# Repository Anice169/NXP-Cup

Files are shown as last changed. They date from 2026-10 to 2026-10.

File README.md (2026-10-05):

# 🏎️ Autonomous Line-Following Car (inspired by the NXP Cup)

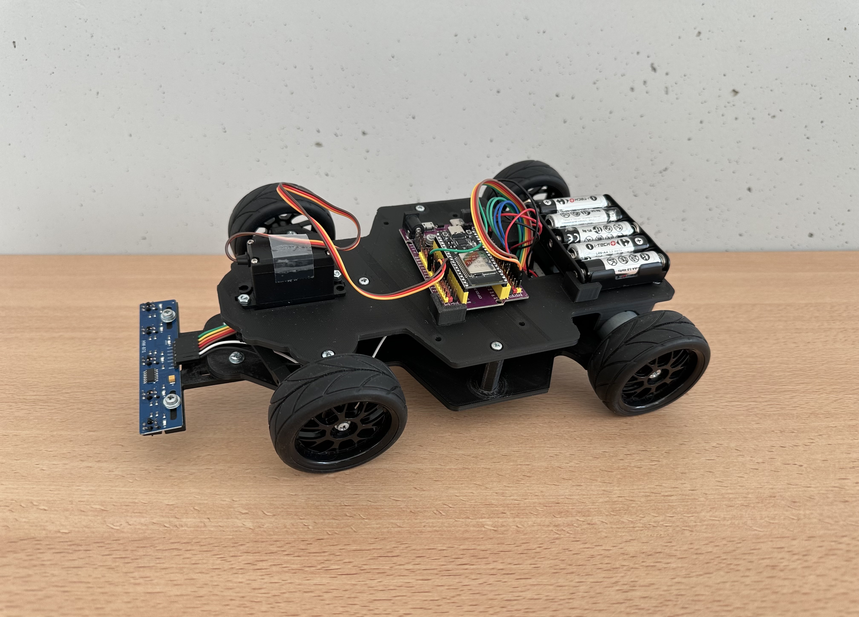
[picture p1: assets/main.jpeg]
Finished car


> Side view of the car once mechanical and electronic assembly was completed.
## 📖 Overview

This project was carried out as part of the 3rd-year project at Polytech Dijon, by a team of three students. We wanted to build skills in embedded electronics and programming, and to discover 3D printing. The NXP Cup inspired us with a concrete goal: building an autonomous car able to follow a line on the ground.

The **NXP Cup** is an international competition organized by NXP Semiconductors, in which teams of students design, build, and program an autonomous miniature vehicle that races around a track as fast as possible. In the official 2025-2026 kit, the car is built on a 3D-printed chassis, driven by an NXP microcontroller, and guided by a camera. More information is available on the [official NXP Cup website](https://nxpcup.nxp.com) and in its [technical GitBook](https://nxp.gitbook.io/nxp-cup).

Rather than using an NXP board, we chose to take on the challenge our own way: we kept the mechanical base of the official kit (motors, servo, wheels, 3D-printed chassis adapted from NXP's files) and redesigned the rest around an **ESP32**.

## 👥 Team

Project carried out by a team of three, as part of the 3rd-year project at Polytech Dijon.

| Member | LinkedIn |
|---|---|
| GUENIAT Anice | [linkedin.com/in/anice-guéniat](https://www.linkedin.com/in/anice-gu%C3%A9niat/) |
| PORTAZ-MONCAYOLA Théo | [linkedin.com/in/theo-portaz-moncayola](https://www.linkedin.com/in/theo-portaz-moncayola/) |
| TENA-FRANCIA Baptiste | [linkedin.com/in/baptiste-tenafrancia](https://www.linkedin.com/in/baptiste-tenafrancia/) |

## 🆚 Official NXP Cup vs. our car

We kept the mechanical base of the official kit and replaced the electronic components that drive the car.

| | Official kit (2025-2026 edition) | Our car |
|---|---|---|
| Control board | NXP board (FRDM-MCXN947, FRDM i.MX93, or S32K144) | ESP32-DevKitC + expansion board |
| Line detection | Pixy2 camera | 5-channel infrared sensor module (TCRT5000) |
| Propulsion | 2 × JGA25-370 motors + DRV8833 drivers | Identical |
| Steering | MG996R servo | Identical |
| Wheels and guidance | 65 mm tires, 12 mm hex couplers, 626ZZ bearing | Identical |
| Power supply | 2S LiPo battery + LM2596 regulators | 5 × AA batteries (motors) + external USB-C battery (electronics) |
| Chassis | 3D-printed (files published by NXP) | 3D-printed from adapted NXP files (see below) |
| Software | NXP tools and examples | C++ (Arduino framework) with PlatformIO |

**Modifications made to the chassis** (based on the 3D files published by NXP):

- Removed the camera mount, no longer needed with infrared sensors
- Added mounts for our components: ESP32 with its expansion board and battery holder
- Added an extension to attach the infrared sensor module, with adjustable height above the ground and distance from the car

## 📸 Demonstration

<p align="center">
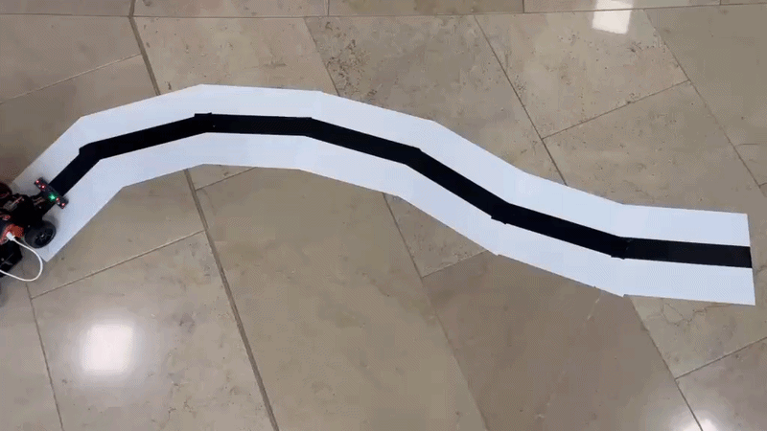
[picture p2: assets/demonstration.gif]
Demonstration of the car following the black line
  <br>
  <em>The car autonomously follows the black line, including curves (top view, about 8 seconds).</em>
</p>

## ✨ Features

- Black line detection using a 5-channel infrared sensor module (TCRT5000)
- Black/white sensor calibration, **saved to flash memory** (no need to recalibrate at every power-up)
- Steering handled by a servo motor
- Propulsion by two geared motors driven through an H-bridge (DRV8833)
- Fully autonomous operation on batteries, with no connection to a computer

## 🔧 Hardware used

| Component | Role |
|---|---|
| ESP32-DevKitC (ESP-WROOM-32) + expansion board | The car's brain: reads the sensors and drives the actuators |
| 5-channel infrared line-following module (TCRT5000) | Detection of the black line on the ground (4 channels used) |
| DRV8833 motor driver (H-bridge) | Controls the speed and direction of the two motors |
| MG996R servo motor | Steering: turns the front wheels |
| 2 × JGA25-370 motors (6 V, 625 rpm) | Propulsion |
| 65 mm tires and 12 mm hex couplers | Wheels and mounting on the motor shafts |
| 626ZZ bearings | Rotation of the front wheels |
| 5 × AA battery holder | Power supply for the motors |
| External USB-C battery | Power supply for the electronics (ESP32, sensors, servo) |
| Breadboard and jumper wires | Wiring |
| 3D-printed chassis (adapted NXP files) | Mechanical structure |

**Software**: VS Code + PlatformIO, Arduino framework for ESP32.

## ⚡ Pinout (ESP32 GPIO)

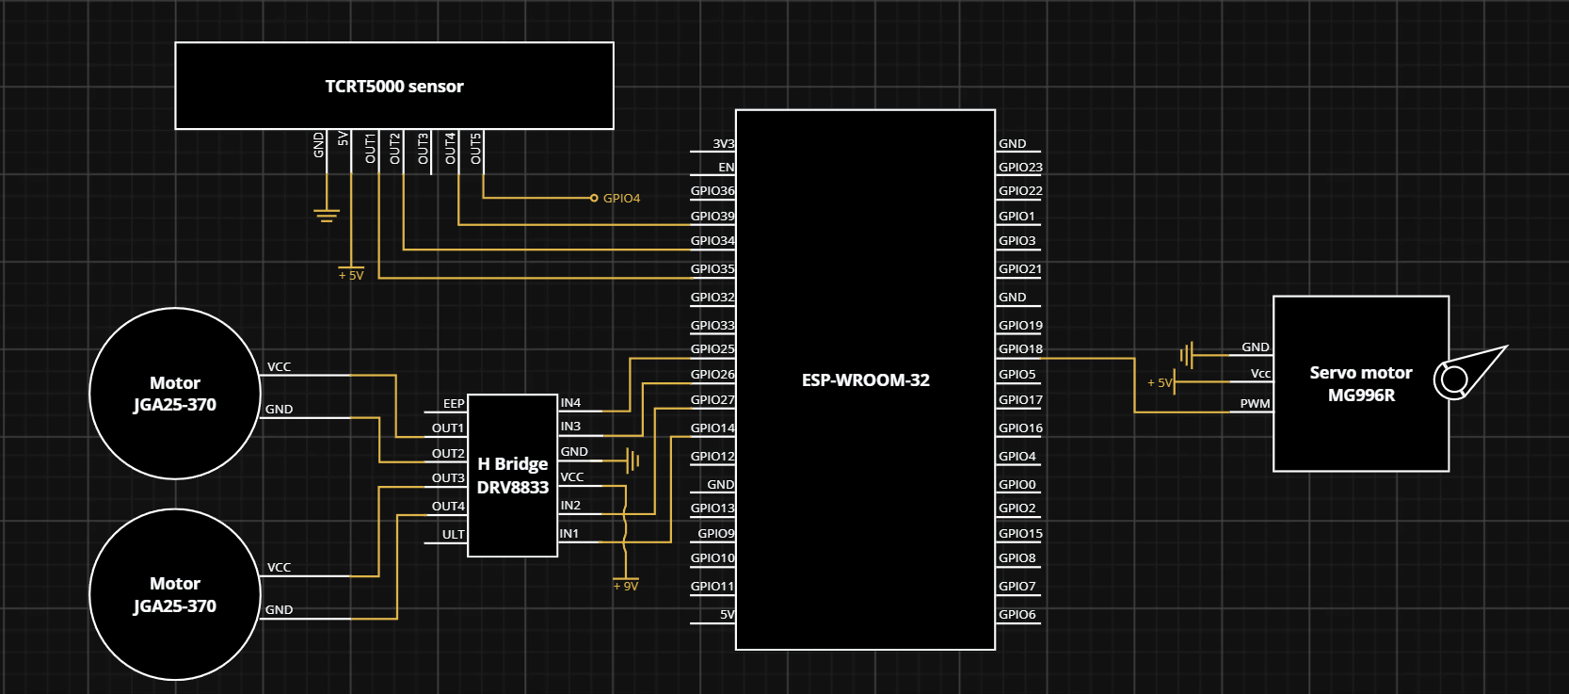
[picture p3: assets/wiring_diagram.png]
Functional circuit diagram

 <!--
| GPIO | Function |
|---|---|
| 25 | DRV8833 — IN1 (motor A) |
| 26 | DRV8833 — IN2 (motor A) |
| 27 | DRV8833 — IN3 (motor B) |
| 14 | DRV8833 — IN4 (motor B) |
| 18 | Servo motor — PWM signal |
| 34 | IR sensor 1 |
| 35 | IR sensor 2 |
| 39 (SVN) | IR sensor 4 |
| 4 | IR sensor 5 |
 -->
> The module's center channel (sensor 3) proved unreliable during the project: it is not used, and the code relies on the 4 remaining channels (1, 2, 4, and 5).
>
> The four DRV8833 inputs receive PWM signals (1 kHz, 8-bit resolution) generated by the ESP32's LEDC peripheral.

## 🧠 How it works
The program (`code/src/main.cpp`) runs in two stages: a startup phase, followed by a decision loop repeated about 20 times per second. The diagram below summarizes how the program works.

```mermaid
flowchart TD
    A["Startup"] --> B{"Calibration<br>in flash memory?"}
    B -- yes --> C["Load calibration<br>+ 10 s to recalibrate with 'c'"]
    B -- no --> D["Guided calibration:<br>white then black"]
    D --> E["Save to flash"]
    C --> F["3 s countdown"]
    E --> F
    F --> G{"More than 100 s<br>since start?"}
    G -- yes --> H["Stop motors<br>servo at 90°"]
    G -- no --> I["Read the 4 sensors<br>normalized from 0 to 1000"]
    I --> J{"Darkest sensor<br>above 300?"}
    J -- no --> K["Servo at 90°:<br>straight ahead"]
    J -- yes --> L["Servo at the angle<br>associated with this sensor"]
    K --> M["Motors at constant speed"]
    L --> M
    M --> N["50 ms pause"]
    N --> G
```

## 🚧 Challenges encountered

- **Fried ESP32**: a mix-up between the 5 V and 3.3 V pins caused short circuit on a board. A multimeter helped us trace the cause of the failure.
- **Insufficient power supply**: the servo motor, the ESP32, and the sensors did not work properly when powered by a single regulated source. We split the power into two supplies: batteries for power (motors) and an external battery for the logic.
- **Unstable center channel on the module**: we gave up using it and adapted the decision algorithm to the 4 remaining channels.
- **Faulty servo motor**: on arrival, one of the servo's gear teeth was defective. We attempted to repair it without success, then ordered a new servo.
- **Broken motor mount**: a 3D-printing defect caused the motor mount to fail on the chassis. We reprinted the part with more robust print settings.

## 🗂️ Repository structure

```
voiture-nxp-cup-esp32/
├── README.md             
├── README.fr.md                  # French readme
├── code/                         # Main code: sensor reading, calibration, control loop
├── cad/                          # 3D Files
└── assets/                       # Pictures

```

## 🚀 Summary and outlook

This project took us through every stage of designing an embedded system: choosing and assembling components, adapting a 3D-printed mechanical structure, programming a microcontroller, and then diagnosing failures, whether from the electronics, the power supply, or a faulty part. The result is a car that follows a line autonomously, and above all a solid foundation to keep building on: finer driving control, speed better adapted to the trajectory, and smarter behavior in unexpected situations are the next steps we're looking forward to.

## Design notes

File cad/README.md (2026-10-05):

# 3D Design – NXP Cup ESP32 Car

This folder contains all the 3D design (CAD) files for the car, created with **Autodesk Fusion 360**.

## Preview

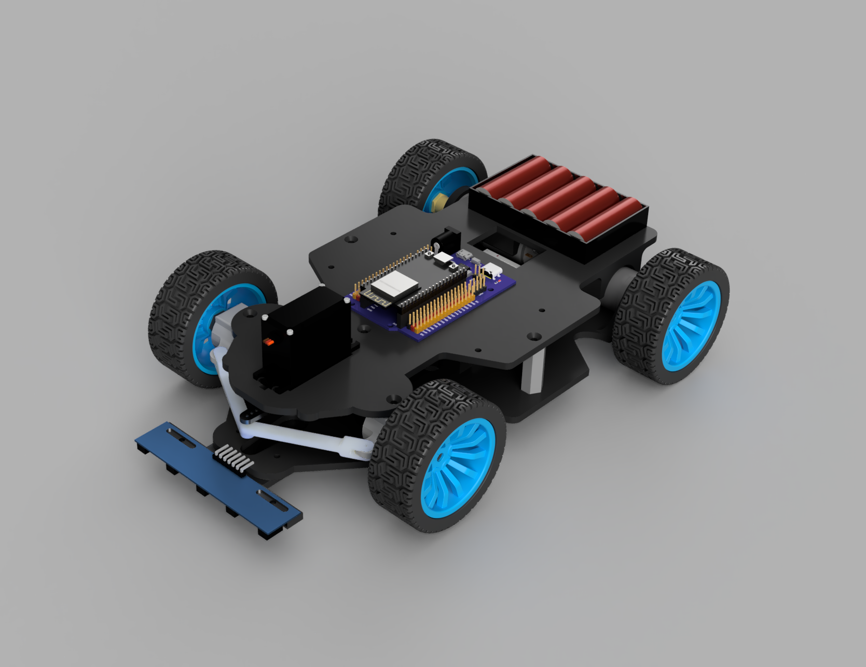
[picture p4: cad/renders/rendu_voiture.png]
3D render of the car


## Folder structure

```
cad/
├── README.md                # This file
├── source/                  # Editable Fusion 360 files (.f3d)
├── step/                    # Universal export (.step)
├── stl/                     # Parts ready for 3D printing
└── renders/                 # Render images
```

| Folder | Content | Purpose |
|---|---|---|
| `source/` | `voiture_complete.f3d` | Original file, editable in Fusion 360 |
| `step/` | `voiture_complete.step` | Neutral format, can be opened with FreeCAD, SolidWorks, Onshape, etc. |
| `stl/` | One part per file | Direct 3D printing, without opening Fusion |
| `renders/` | PNG images | Project presentation |

## Parts list

| Part | STL file | Quantity | Role |
|---|---|---|---|
| Bottom plate | `BottomPlate_Bottomplate.stl` | 1 | Base of the chassis, on which the components are mounted |
| Top plate | `plaque_hautV3.stl` | 1 | Upper deck of the chassis |
| Hex spacer | `Chassis_HexSpacer.stl` | 5 | Keeps the two chassis plates apart |
| Left steering arm | `Arm Steering left.stl` | 1 | Steering arm for the front left wheel |
| Right steering arm | `Arm steering right.stl` | 1 | Steering arm for the front right wheel |
| Front wheel hex adapter | `Steering_HexAdapterFrontWh….stl` | 2 | Connects the front wheel to its axle |
| Steering linchpin | `Steering_Linchpin.stl` | 2 | Locks the steering axle in place |
| Steering shaft | `Steering_SteerShaft.stl` | 2 | Pivot axle of the steering |
| Sensor mount | `support capteur.stl` | 1 | Sensor mounting bracket |
| Mount | `support.stl` | 1 | Bracket used to attach components to the chassis |

## Usage

### Editing the design
1. Open Fusion 360.
2. Go to `File > Open > Open from my computer`.
3. Select `source/voiture_complete.f3d`.

### Using another CAD software
Import the file `step/voiture_complete.step` (FreeCAD, SolidWorks, Onshape, etc.).

### Printing a part
Open the desired `.stl` file in your slicer (Cura, PrusaSlicer, Bambu Studio...) and start the print.

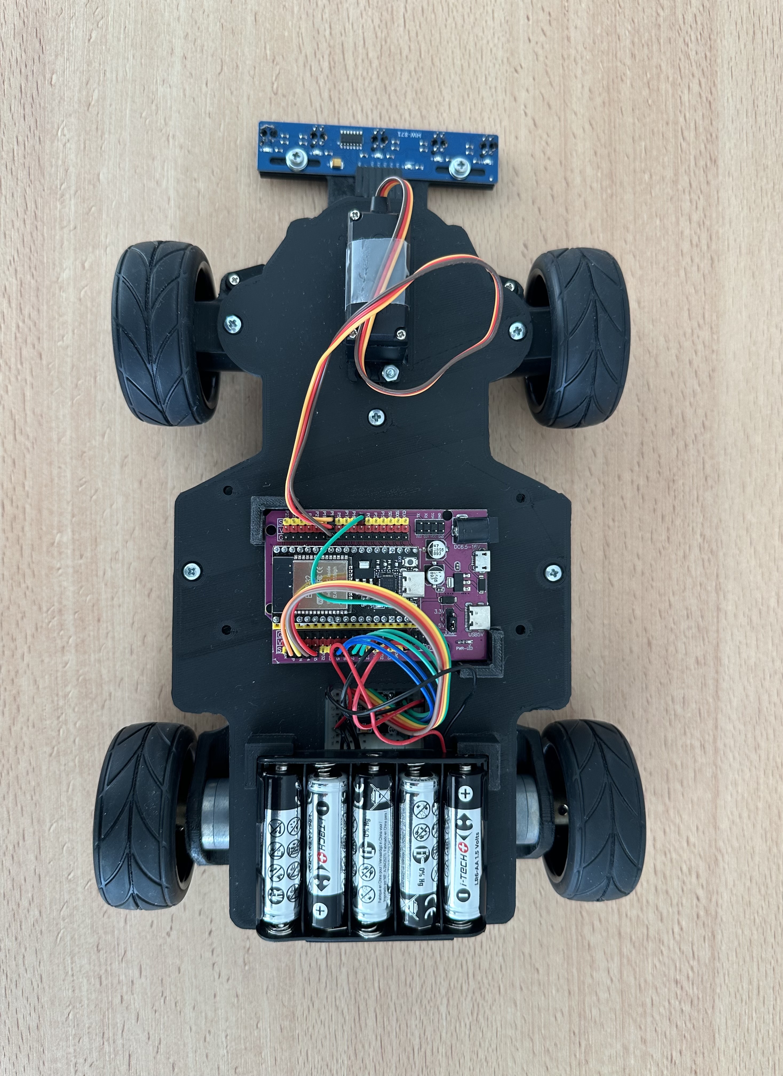
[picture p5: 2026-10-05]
assets/top.jpeg

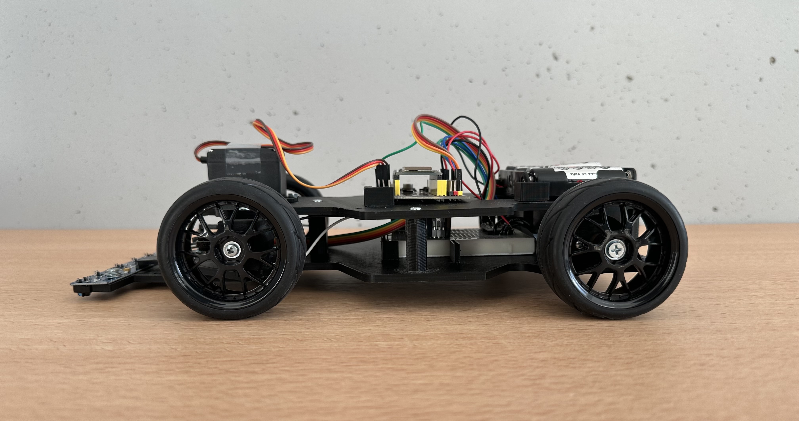
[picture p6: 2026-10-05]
assets/side.jpeg

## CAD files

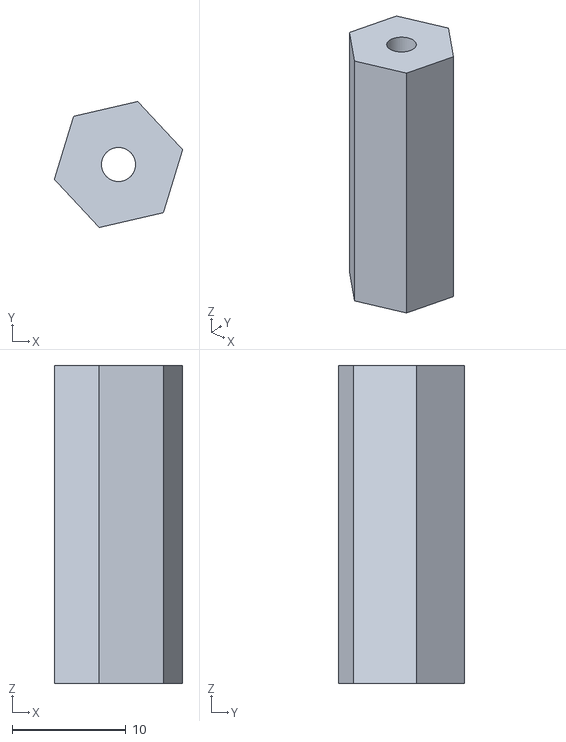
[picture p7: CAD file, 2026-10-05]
cad/stl/Chassis_HexSpacer.stl
11.3 x 11.1 x 28.0

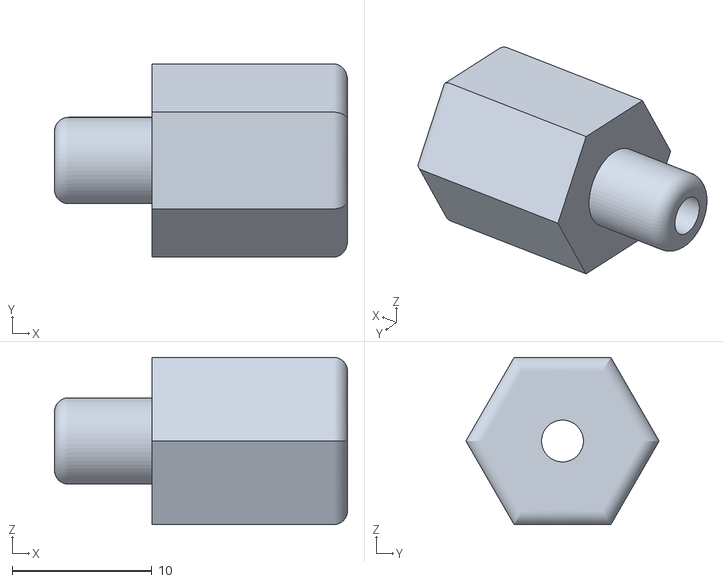
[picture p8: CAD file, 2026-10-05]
cad/stl/Steering_HexAdapterFrontWheel(6mmx12mmhex).stl
21.0 x 13.9 x 12.0

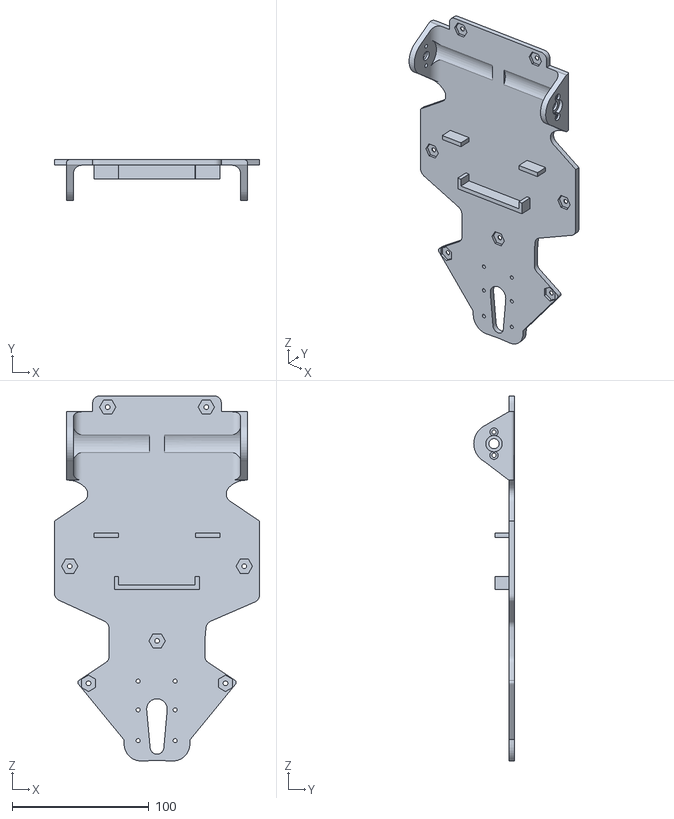
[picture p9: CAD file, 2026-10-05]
cad/stl/BottomPlate_Bottomplate.stl
150.0 x 29.6 x 266.5

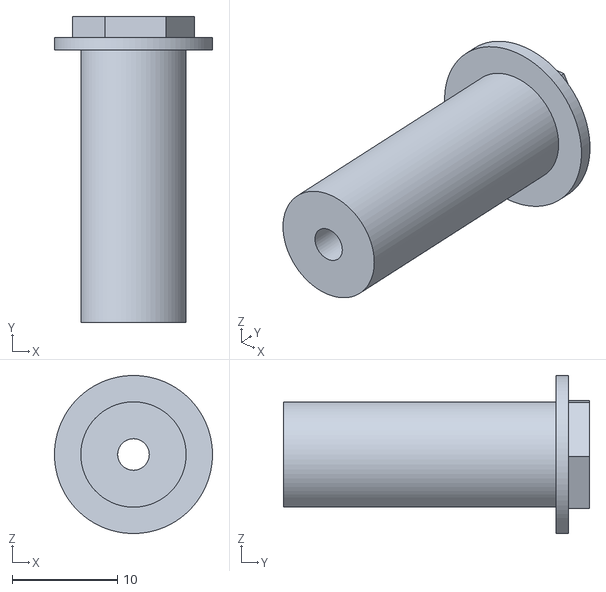
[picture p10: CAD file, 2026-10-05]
cad/stl/Steering_SteerShaft.stl
15.0 x 29.1 x 15.0

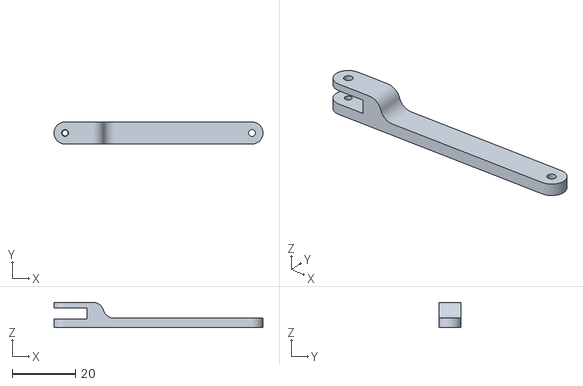
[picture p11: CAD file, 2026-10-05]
cad/stl/Arm steering right.stl
66.0 x 7.00 x 8.00

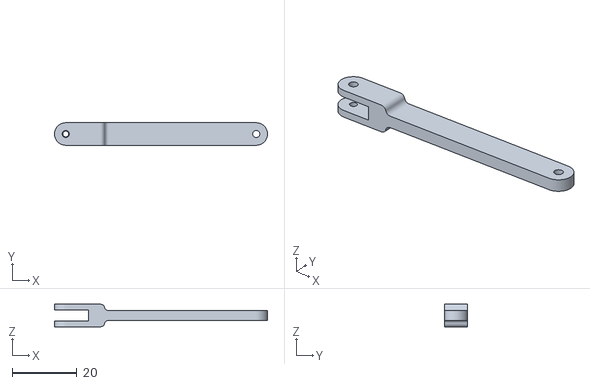
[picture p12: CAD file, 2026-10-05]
cad/stl/Arm Steering left.stl
66.0 x 7.00 x 7.00

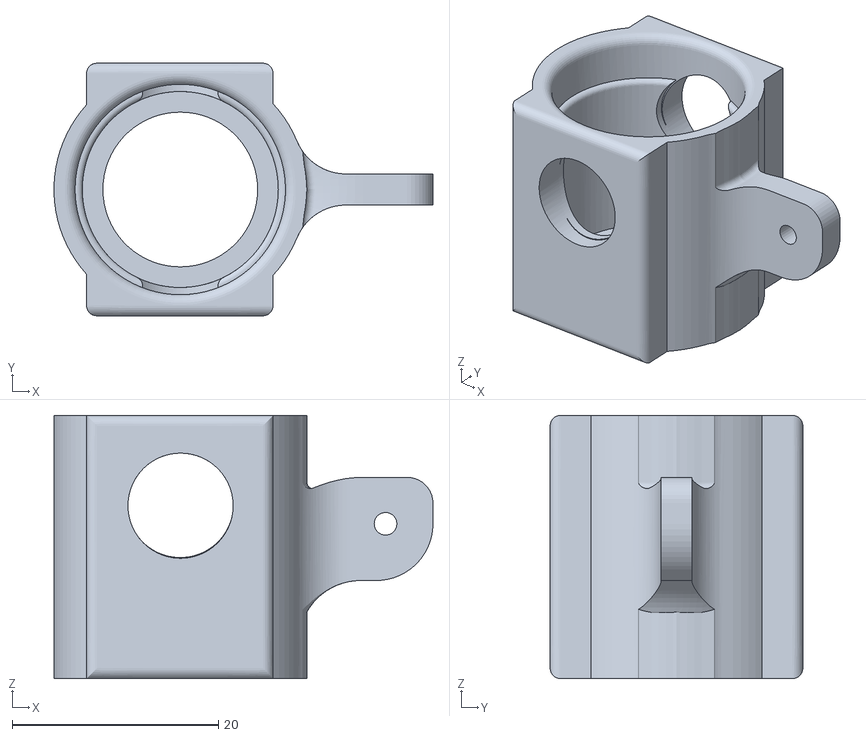
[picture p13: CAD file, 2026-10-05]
cad/stl/Steering_Linchpin.stl
36.7 x 24.5 x 25.5

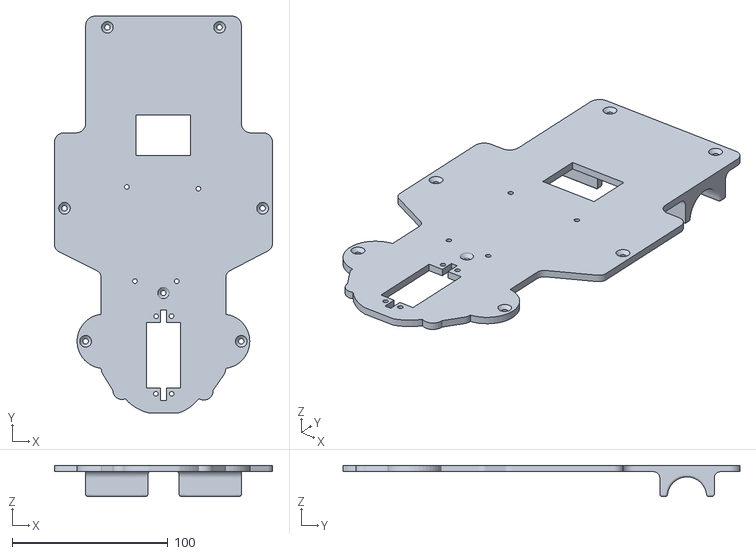
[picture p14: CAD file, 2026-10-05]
cad/stl/plaque_hautV3.stl
140.1 x 255.0 x 20.0

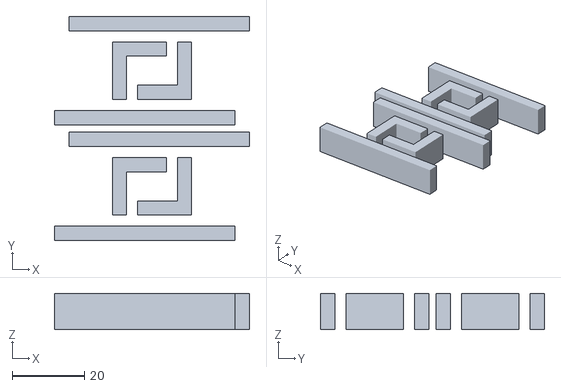
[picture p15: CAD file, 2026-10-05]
cad/stl/support.stl
54.0 x 62.0 x 10.0

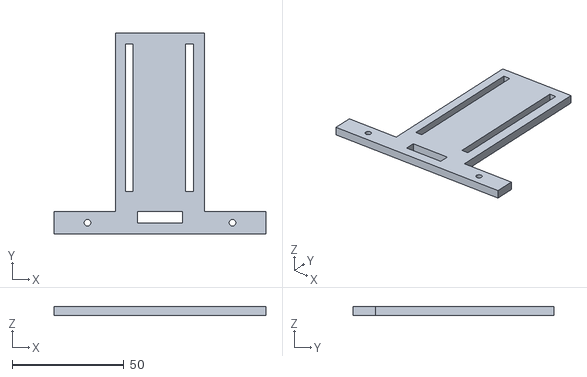
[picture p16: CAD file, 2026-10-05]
cad/stl/support capteur.stl
95.0 x 90.0 x 4.00

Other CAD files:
cad/step/voiture_complete.step
cad/source/voiture_complete.f3z

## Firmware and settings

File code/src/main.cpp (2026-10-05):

/*
 * ============================================================================
 *  Voiture autonome suiveuse de ligne (inspirée de la NXP Cup)
 *  Projet de 3e année - Polytech Dijon
 * ----------------------------------------------------------------------------
 *  Principe : au démarrage, on charge (ou on réalise) la calibration
 *  blanc/noir des capteurs. Ensuite, toutes les 50 ms, on repère le capteur
 *  qui voit le plus de noir et on oriente le servomoteur selon un angle
 *  prédéfini, pendant que les deux moteurs tournent à vitesse constante.
 *  La voiture s'arrête automatiquement au bout de DUREE_MAX.
 *
 *  Les valeurs que l'on peut modifier pour ajuster le comportement sont
 *  repérées par le marqueur [À RÉGLER]. Les voici :
 *    - VITESSE                    : vitesse des moteurs (0 à 255)
 *    - DUREE_MAX                  : durée avant l'arrêt automatique (ms)
 *    - le seuil de détection      : 300 sur 1000, dans loop()
 *    - les angles du servomoteur  : 70 / 90 / 130 / 150, dans loop()
 *    - la pause entre deux cycles : 50 ms, dans loop()
 *    - la fenêtre de recalibration (10 s) et le décompte de départ (3 s),
 *      dans setup()
 *    - le nombre de mesures moyennées : paramètre n de lireMoyenne()
 *    - le sens de rotation des moteurs, dans avancer()
 * ============================================================================
 */

#include <Arduino.h>
#include <ESP32Servo.h>    // Pilotage du servomoteur (version de la bibliothèque adaptée à l'ESP32)
#include <Preferences.h>   // Sauvegarde de valeurs en mémoire flash (zone NVS)

// ---------------------------------------------------------------------------
//  Brochage (numéros de GPIO de l'ESP32)
// ---------------------------------------------------------------------------

// Sorties analogiques du module de suivi de ligne.
// La voie 3 (centrale, GPIO 36) n'est volontairement pas utilisée : elle s'est
// révélée peu fiable. Les GPIO 34, 35 et 39 sont des entrées uniquement (ADC1).
// Le GPIO 4 est sur l'ADC2, utilisable ici car le Wi-Fi n'est pas activé.
#define CAPTEUR_1  34
#define CAPTEUR_2  35
#define CAPTEUR_4  39
#define CAPTEUR_5  4

// Signal de commande (PWM) du servomoteur de direction
#define PIN_SERVO  18

// Entrées du DRV8833 : A1 et A2 pour le moteur A (IN1 / IN2),
// B1 et B2 pour le moteur B (IN3 / IN4)
#define MOTEUR_A1  25
#define MOTEUR_A2  26
#define MOTEUR_B1  27
#define MOTEUR_B2  14

// ---------------------------------------------------------------------------
//  Variables et constantes globales
// ---------------------------------------------------------------------------

// Les 4 capteurs utilisés, dans l'ordre de gauche à droite (voies 1, 2, 4, 5)
const int capteurs[4] = {CAPTEUR_1, CAPTEUR_2, CAPTEUR_4, CAPTEUR_5};

// Valeurs brutes lues par chaque capteur sur le blanc et sur le noir
// (renseignées par la calibration, de 0 à 4095 car l'ADC de l'ESP32 est sur 12 bits)
int ref_blanc[4];
int ref_noir[4];

Servo monServo;      // Objet qui pilote le servomoteur
Preferences prefs;   // Objet qui lit/écrit dans la mémoire flash

// [À RÉGLER] Vitesse des moteurs : rapport cyclique PWM de 0 (arrêt) à 255 (maximum).
// 140 correspond à environ 55 %. Trop élevée, la voiture sort des virages.
const int VITESSE = 140;

// [À RÉGLER] Durée maximale de fonctionnement avant l'arrêt automatique de
// sécurité, en millisecondes (100000 ms = 100 secondes)
const int DUREE_MAX = 100000;

unsigned long tempsDepart;   // Instant (en ms) du départ de la voiture

// ---------------------------------------------------------------------------
//  Lecture des capteurs
// ---------------------------------------------------------------------------

// Lit un capteur n fois et renvoie la moyenne, pour réduire le bruit de mesure.
// [À RÉGLER] n = 50 mesures espacées de 2 ms (soit environ 0,1 s par capteur).
int lireMoyenne(int broche, int n = 50) {
  long total = 0;
  for (int i = 0; i < n; i++) {
    total += analogRead(broche);
    delay(2);
  }
  return total / n;
}

// ---------------------------------------------------------------------------
//  Calibration
// ---------------------------------------------------------------------------

// Mesure la valeur de chaque capteur sur une surface de référence ("BLANC" ou
// "NOIR") et la range dans le tableau valeurs[].
// Attention : la fonction est bloquante, elle attend un appui sur ENTRÉE dans
// le moniteur série. Elle n'est donc utilisable qu'avec l'USB branché.
void calibrer(int valeurs[4], const char *nom) {
  Serial.print("\n>>> Place le module sur ");
  Serial.print(nom);
  Serial.println(" puis appuie sur ENTREE...");
  while (Serial.available() == 0) { delay(10); }       // Attente de l'appui sur ENTRÉE
  while (Serial.available() > 0) { Serial.read(); }    // Vide la mémoire de réception
  Serial.println("Calibration en cours...");
  for (int i = 0; i < 4; i++) {
    valeurs[i] = lireMoyenne(capteurs[i]);
    Serial.print("Capteur ");
    Serial.print(i + 1);
    Serial.print(" : ");
    Serial.println(valeurs[i]);
  }
}

// Enregistre la calibration en mémoire flash pour qu'elle survive à une coupure
// d'alimentation. Les valeurs sont rangées dans l'espace de noms "calib" :
//   b0..b3 = valeurs sur le blanc, n0..n3 = valeurs sur le noir,
//   ok     = drapeau indiquant qu'une calibration existe.
// À n'appeler qu'après une calibration : le nombre d'écritures en flash est limité.
void sauvegarderCalibration() {
  prefs.begin("calib", false);   // false = lecture et écriture
  for (int i = 0; i < 4; i++) {
    prefs.putInt(("b" + String(i)).c_str(), ref_blanc[i]);
    prefs.putInt(("n" + String(i)).c_str(), ref_noir[i]);
  }
  prefs.putBool("ok", true);
  prefs.end();
  Serial.println("Calibration sauvegardee !");
}

// Recharge la calibration depuis la mémoire flash.
// Renvoie true si une calibration existait, false sinon (première utilisation).
bool chargerCalibration() {
  prefs.begin("calib", true);    // true = lecture seule
  bool ok = prefs.getBool("ok", false);
  if (ok) {
    for (int i = 0; i < 4; i++) {
      // Les deuxièmes arguments (0 et 1000) sont les valeurs par défaut
      // renvoyées si une clé est introuvable.
      ref_blanc[i] = prefs.getInt(("b" + String(i)).c_str(), 0);
      ref_noir[i]  = prefs.getInt(("n" + String(i)).c_str(), 1000);
    }
  }
  prefs.end();
  return ok;
}

// ---------------------------------------------------------------------------
//  Commande des moteurs
// ---------------------------------------------------------------------------
// Les 4 entrées du DRV8833 sont pilotées par des canaux PWM (LEDC) numérotés
// 4 à 7 : 4 = A1, 5 = A2, 6 = B1, 7 = B2 (voir setup()).
// Pour avancer, A1 et B1 reçoivent la vitesse tandis que A2 et B2 restent à 0.
// [À RÉGLER] Si un moteur tourne à l'envers, on peut inverser ses deux fils ou
// échanger les rôles des canaux 4/5 (moteur A) ou 6/7 (moteur B) ci-dessous.

void avancer(int vitesse) {
  ledcWrite(4, vitesse);
  ledcWrite(5, 0);
  ledcWrite(6, vitesse);
  ledcWrite(7, 0);
}

// Coupe les quatre entrées : les moteurs ne sont plus alimentés (roue libre)
void arreter() {
  ledcWrite(4, 0);
  ledcWrite(5, 0);
  ledcWrite(6, 0);
  ledcWrite(7, 0);
}

// ---------------------------------------------------------------------------
//  Initialisation (exécutée une seule fois à la mise sous tension)
// ---------------------------------------------------------------------------
void setup() {
  // Liaison série pour le débogage. La vitesse (115200) doit être la même que
  // "monitor_speed" dans platformio.ini.
  Serial.begin(115200);
  delay(500);

  // Configuration du PWM des moteurs avec l'ancienne API LEDC (Arduino core
  // ESP32 2.x) : ledcSetup(canal, fréquence en Hz, résolution en bits), puis
  // ledcAttachPin(broche, canal). Ici 1 kHz sur 8 bits (valeurs de 0 à 255).
  // Les canaux 4 à 7 évitent les premiers canaux, que la bibliothèque
  // ESP32Servo peut utiliser pour le servomoteur.
  ledcSetup(4, 1000, 8); ledcAttachPin(MOTEUR_A1, 4);
  ledcSetup(5, 1000, 8); ledcAttachPin(MOTEUR_A2, 5);
  ledcSetup(6, 1000, 8); ledcAttachPin(MOTEUR_B1, 6);
  ledcSetup(7, 1000, 8); ledcAttachPin(MOTEUR_B2, 7);
  arreter();   // Sécurité : moteurs à l'arrêt tant que la calibration n'est pas faite

  monServo.attach(PIN_SERVO);
  monServo.write(90);   // Direction centrée au démarrage

  if (chargerCalibration()) {
    // Une calibration est déjà enregistrée : on laisse la possibilité d'en refaire une
    Serial.println("Calibration chargee !");
    Serial.println("Envoie 'c' pour recalibrer, sinon depart dans 10s...");
    unsigned long t = millis();
    // [À RÉGLER] Fenêtre de recalibration : 10000 ms (10 secondes)
    while (millis() - t < 10000) {
      if (Serial.available() && Serial.read() == 'c') {
        Serial.println("=== Recalibration ===");
        calibrer(ref_blanc, "BLANC");
        calibrer(ref_noir, "NOIR");
        sauvegarderCalibration();
        break;
      }
    }
  } else {
    // Aucune calibration en mémoire (première utilisation) : on la réalise
    Serial.println("=== Premiere calibration ===");
    calibrer(ref_blanc, "BLANC");
    calibrer(ref_noir, "NOIR");
    sauvegarderCalibration();
  }

  // [À RÉGLER] Décompte avant le départ : 3000 ms (3 secondes), le temps de
  // poser la voiture sur la piste
  Serial.println("=== Depart dans 3 secondes ===");
  delay(3000);
  tempsDepart = millis();
}

// ---------------------------------------------------------------------------
//  Boucle principale (répétée en continu, environ 20 fois par seconde)
// ---------------------------------------------------------------------------
void loop() {
  // --- 1. Arrêt automatique de sécurité ------------------------------------
  // Une fois DUREE_MAX écoulée, on coupe les moteurs, on recentre la direction
  // et on bloque le programme (il faut redémarrer la carte pour repartir).
  if (millis() - tempsDepart > DUREE_MAX) {
    arreter();
    monServo.write(90);
    Serial.println("=== ARRET automatique ===");
    while (true);
  }

  // --- 2. Lecture et normalisation des capteurs ----------------------------
  // Chaque valeur brute est ramenée à une échelle de 0 (blanc) à 1000 (noir)
  // grâce aux valeurs de calibration. Cela compense les écarts entre capteurs.
  int norm[4];
  for (int i = 0; i < 4; i++) {
    int brut = analogRead(capteurs[i]);
    norm[i] = map(brut, ref_blanc[i], ref_noir[i], 0, 1000);
    norm[i] = constrain(norm[i], 0, 1000);   // Évite de sortir de l'intervalle 0-1000
  }

  // Affichage de débogage (utile pour régler les seuils avec l'USB branché)
  Serial.print("Capteurs: ");
  for (int i = 0; i < 4; i++) {
    Serial.print(norm[i]);
    Serial.print("\t");
  }

  // --- 3. Détection : recherche du capteur qui voit le plus de noir ---------
  int maxVal = 0;     // Plus grande valeur normalisée trouvée
  int maxIdx = -1;    // Indice du capteur correspondant (0 à 3)
  for (int i = 0; i < 4; i++) {
    if (norm[i] > maxVal) {
      maxVal = norm[i];
      maxIdx = i;
    }
  }

  // --- 4. Direction : choix de l'angle du servomoteur -----------------------
  // [À RÉGLER] Seuil de détection : sous 300 sur 1000, on considère qu'aucun
  // capteur ne voit la ligne et on va tout droit.
  //
  // [À RÉGLER] Angles du servomoteur (en degrés) : 70 / 90 / 130 / 150.
  // Ces valeurs ont été trouvées par essais. Elles ne sont pas symétriques
  // autour de 90° car le parallélisme des roues avant n'est pas parfait : avec
  // des angles symétriques, la voiture ne roulait pas droit. Si la voiture dérive
  // ou si la mécanique change, ce sont ces valeurs qu'il faut ajuster.
  // D'après le montage actuel, un angle inférieur à 90° braque à gauche et un
  // angle supérieur à 90° braque à droite. Les libellés affichés dans le
  // moniteur série ("Gauche", "Droite") sont indicatifs.
  int angle;
  if (maxVal < 300) {
    angle = 90;
    Serial.print("-> Tout droit");
  } else {
    switch (maxIdx) {
      case 0: angle = 70; Serial.print("-> Gauche max"); break;   // Capteur 1
      case 1: angle = 90; Serial.print("-> Gauche");     break;   // Capteur 2
      case 2: angle = 130;  Serial.print("-> Droite");     break; // Capteur 4
      case 3: angle = 150;  Serial.print("-> Droite max"); break; // Capteur 5
    }
  }

  // --- 5. Commande des actionneurs -----------------------------------------
  monServo.write(angle);   // Oriente la direction
  avancer(VITESSE);        // Les deux moteurs tournent à vitesse constante
  Serial.print(" -> Angle: ");
  Serial.println(angle);

  // [À RÉGLER] Pause entre deux cycles : 50 ms, soit environ 20 décisions par
  // seconde. Une pause plus courte rend la voiture plus réactive, mais envoie
  // plus de messages sur la liaison série.
  delay(50);
}
